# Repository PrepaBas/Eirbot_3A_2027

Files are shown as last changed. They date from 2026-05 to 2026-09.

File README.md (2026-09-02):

# EIRBOT 3A 2027
## Equipe
### OG
- Barthere Aurelien E3
- Bromet Alexandre E3
- Daragnes Leïa I3
- Guigui Marceau E3
- Halimi Zakaria E3
- Louvel Elise E3
- Marie Quentin E3
- Tran-Ruesche Bastien E3

#### A traquenard
- Berthod Hugo E3
- Donias Arno I3
- Michaud Lou-Ann E3
- Maxime Lavit E3
- Joan Dumarchat I3 (bientôt)

#### Refus
- 

## Compilation micro-ros
checkout to humble then go back to main folder and
``` bash
docker pull microros/micro_ros_static_library_builder:humble
docker run -it --rm -v $(pwd):/project --env MICROROS_LIBRARY_FOLDER=micro_ros_stm32cubemx_utils/microros_static_library microros/micro_ros_static_library_builder:humble
```

## Debug config
debug : Cortex-Debug dans vs code
+ `sudo apt install openocd`
+ fichier `.vscode/launch.json`
```json
{
    "version": "0.2.0",
    "configurations": [
        {
            "name": "Debug STM32H533 (micro-ROS)",
            "type": "cortex-debug",
            "request": "launch",
            "servertype": "openocd",
            "cwd": "${workspaceRoot}",
            "executable": "${workspaceRoot}/build/microros_base.elf",
            "device": "STM32H533RE", // Ajuste si la référence exacte de ton H5 change
            "configFiles": [
                "interface/stlink.cfg",
                "target/stm32h5x.cfg"
            ],
            // --- TRÈS IMPORTANT POUR EUROBOT & FREERTOS ---
            "rtos": "FreeRTOS", // Permet à VS Code de voir tes différentes tâches (Odom, micro-ROS...)
            "runToEntryPoint": "main", // S'arrête automatiquement au début du main()
            "openOCDPreConfigLaunchCommands": [
                "set CONNECT_UNDER_RESET 1" // Évite le piège du blocage de la puce !
            ]
        }
    ]
}
```
## Esthétique du robot
???
## Méca
### Structure
Une plaque de 5mm (acrilique, aluminium ou acier) de 250x250mm avec les coins coupés à 5mm du sol. une bille principale à l'arrière et des patins de protection partout autour. (A voir pour une plaque de 240x240mm mais en rajoutant du flexible en protection).  
Des makerbeam (extrusion aluminium de 10x10mm) s'attachent à la plaque horizontalement et une tour de quatre extrusions s'élève jusqu'à h=30mm. En haut, d'autres extrusions forment une base pour monter l'électronique, un écran, une balise, l'aru...

### Bloc moteur
Stepper Nema 17 avec encodeuse As5047p. Contrôlé (FOC) par ST B-g431Esc suivant le modèle HybridStepper de SimpleFOC.  
Roue encodeuse sur table suspendue par deux rails linéaires MGN9H, MGN12C ou MGN12H. Roues sur deux roulements et encodée avec le capteur magnétique As5047p encore une fois. Force linéaire descendante avec des élastiques de bureau.  
Cet ensemble s'attache à la plaque du dessous. Les vis sont fraisées et montée par le dessous. L'alignement est à voir. 
Roues de romba ou tube silicon ou silicon de cuisine...

### Matériaux
Du plastique imprimé en 3D / de l'acrylique découpé à la laser et eventuellement du métal si on a les moyens vers la fin.
Des makerbeam pour tout le reste du structurel.

### Visserie
du chc de préference

## Elec
### Puissance
J'ai deux batteries lipo 4s (15V) mais ca va être compliqué de mettre les deux sur le robot parce qu'elles sont grosses. Donc robot en 12V à part si on trouve une solution pour caser les deux / racheter des batteries plus petites.  
prévoir 
- 5.2V 5A en USB-C pour la rasp
- 2x 12V 2.5A pour les moteurs (et pas mal de réserve en pic)
- rails 12V et 5V pour actionneurs et capteurs

##### Et eventuellement
- 5V 0.5A en USB-C pour la STm
- 

#### Connectique
XT-30 : femelle donne et mâle reçoit.

#### Protection
Fusible au moins mais je ne m'y connais pas

### Logique
Acheter des fils petits c'est beaucoup mieux. JST 2.5mm c'est pour l'instant le plus pratique même si c'est gros

### Ventilation
Ce serai bien d'en mettre

## Info
### Rasp
#### Ecran
Ecran tactile si possible avec une interface graphique (html par exemple) qui permet d'executer des scripts.

#### ROS2
Framwork Ros2 dans un docker pour pouvoir laisser raspOS en natif. Le but est de commencer à écrire nos propres nodes. La strat générale c'est d'utiliser les Behavior Tree pour séquencer les actions : il faut donc faire des serveurs
- rotation
- ligne droite
- path planning sommaire pour éviter nav2
- actionneurs

Il faut aussi faire la détection et tout enfin bref une belle galère.  
Exit gazebo vive rviz tout court  

EKF pour les roues odometriques, l'imu et autre si affinité.

Exit le controller differentiel de ros, ca se fera sur mcu.

#### Behavior Tree
Permet de rendre le robot dynamique. Par exemple, recherche d'un goal, séquence pour arriver au goal, maneuvre et actionneurs et rebelotte. Si un obstacle est détecté, on peut attendre et réessayer avant de revenir au choix de l'action.

Dans l'idéal il y a un serveur en python (rasp) et un serveur en c++ (mcu) pour distinguer la simu du réel.

### MCU
STM32 mp1814C qui embarque un st32h533re bien balèze. Host micro-ros pour communiquer avec le ros2 de la rasp. 
Programmation hors framework Arduino donc avec la synthaxe ST et la configuration sur CubeMX. L'utilisation de micro-ros 'impose' une toolchain Makefile.  
Le MCU doit gérer : 
- Envoi des commandes CAN de vitesse aux ESC
- Reception des données encodeuses. Signaux AB récupérés avec les timers en mode encoder.
- Asserv rapide et capacité de tourner, avancer (voir se déplacer dans le plan mais on est pas encore là).
- Récupération via SPI de l'IMU **ICM42688**
- Récupération des données TOF si il y a
- Gestion des timeout, de l'évitement de poing, du timer de 100 secondes : il faut donc plusieurs modes pour le debug et le match (pourquoi pas un topic)
- des serveurs pour tourner, avancer et faire marcher les actionneurs.

## Evitement
Un lidar si on veut, branché sur la rasp et qui permet de faire de l'évitement longue distance  
Des tof branchés au MCU pour la défense de poing.

Dans le meilleur des mondes des zones (devant près, devant loin, droite près ...) pour éviter de tourner avec les actionneurs déployés.

## Répartition des tâches
Le robot contient deux centres de calculs principaux : le microcontroleur et le microprocesseur.  
> **Le processeur** gère la stratégie haut niveau, la connectivité réseau et l'aquisition et traitement lidar.

> **Le controlleur** gère le controle moteur, l'estimation de position à partir de [encodeuse, centrale inertielle, position absolue résultant du traitement lidar].

Pourquoi? Le controlleur doit gérer le controle moteur le plus précisement possible, et à donc besoin de faire ses calculs en temps réel le plus possible. Le processeur est utile surtout pour la connectivité et sa puissance de calcule au détriment du temps réel. Pour cela ce dernier est réserver à la strat et traitement lidar qui sont respectivement peu critique et lourd en calculs.  
Eventuellement le controlleur peut avoir des élements de détection rapprochés type tof pour une sécurité supplémentaire, et le processeur un algorithme de path planning pour générer des trajectoires courbes.

```Mermaid
C4Component
    title Diagramme C4 - Architecture Microcontrôleur & Raspberry Pi

    System_Boundary(main_robot, "Robot Principal", "Gros robot", "rien") {

        Component_Ext(mag_sens, "As5047p", "Capteur", "Capteur magnétique angle absolue")
        Component_Ext(imu_sens, "ICM42688", "Capteur", "Acceleromètre et gyroscope")
        Component_Ext(lidar, "RPLidar C1", "Capteur", "LIDAR")

        Container_Boundary(mcu, "Microcontrôleur STM32 (Micro-ROS)") {
            Component(t_as5047p, "Encoder-mode Timers", "Hardware", "Aqueri les signaux AB des encodeurs")
            Component(t_imu, "IMU DMA", "Hardware / RTOS Task", "Aqueri les données inertielles")
            Component(t_mot, "Tâche Moteur", "RTOS Timer", "Calcule la vitesse des moteurs (~100Hz)")
            Component(t_sens, "Kalman Filter", "Function", "Lit les données des capteurs physiques")
        }
        Container_Boundary(rpi, "Raspberry Pi (ROS2) ") {
            Component(t_lidar, "sllidar", "Ros2 Node", "Interface le RPLidar-C1 avec Ros2")
            Component(t_obj_det, "Object Detection", "Ros2 Node", "Extrait des formes depuis les données LIDAR")
            Component(t_trig, "Triangulation Balises", "Custom Ros2 Node", "Extrait une position absolue des objets détectés par le LIDAR")
            Component(t_adv_det, "Triangulation Adversaire", "Custom Ros2 Node", "Extrait une position absolue de l'adversaire")
        }
        Container_Boundary(mot, "Bloc Moteur") {
        Component_Ext(esc, "Bg431ESC", "Controlleur de viteses", "Contrôle les moteurs FOC (~20kHz)")
        Component_Ext(mag_sens_esc, "As5047p", "Capteur magnétique", "Angle absolue des roues")
        }
    }    

    %% Communications internes RPi
    Rel(t_lidar, t_obj_det, "Scan")
    Rel_L(t_obj_det, t_trig, "obj")
    Rel_R(t_obj_det, t_adv_det, "obj")
    
    %% Communication internes MCU
    Rel_D(t_sens, t_mot, "pose")
    Rel_D(t_imu, t_sens, "pose")
    Rel_D(t_as5047p, t_sens, "pose")

    %% Communications Rasp - MCU
    Rel_L(t_trig, t_sens, "lidar pose")

    %% Communication internes ESC
    Rel(mag_sens_esc, esc, "SPI : angle absolu")

    %% Communication Robot - MCU
    Rel(t_mot, esc, "CAN : vitesse des roues")
    Rel(mag_sens, t_as5047p, "Signaux AB")
    Rel(imu_sens, t_imu, "SPI")

    %% Communication Robot - Rasp
    Rel(lidar, t_lidar, "câble USB")

```

``` Mermaid
graph TD
    %% Node Styles
    classDef selector fill:#f9f,stroke:#333,stroke-width:2px;
    classDef sequence fill:#bbf,stroke:#333,stroke-width:2px;
    classDef condition fill:#ff9,stroke:#333,stroke-width:1px;
    classDef action fill:#9f9,stroke:#333,stroke-width:1px;

    %% --- LEGEND ---
    subgraph Legend ["Tree Legend"]
        direction LR
        L1{?}:::selector === L1_T["Selector (Runs until a child SUCCEEDS)"]
        L2[➔]:::sequence === L2_T["Sequence (Runs until a child FAILS)"]
        L3([Condition]):::condition === L3_T["Check / State Test"]
        L4[[Action]]:::action === L4_T["Execution / Behavior"]
    end

    %% --- BEHAVIOR TREE ---
    Root((Root)) --> Selector1{?}:::selector
    
    %% Fallback 1: Attack Branch
    Selector1 --> Sequence1[➔ Sequence: Fight]:::sequence
    Sequence1 --> Cond1([Is Enemy Close?]):::condition
    Sequence1 --> Act1[[Attack Enemy]]:::action
    
    %% Fallback 2: Patrol Branch
    Selector1 --> Sequence2[➔ Sequence: Patrol]:::sequence
    Sequence2 --> Cond2([Is Energy High?]):::condition
    Sequence2 --> Act2[[Move to Waypoint]]:::action
    
    %% Fallback 3: Rest Branch
    Selector1 --> Act3[[Sleep/Recover]]:::action
```

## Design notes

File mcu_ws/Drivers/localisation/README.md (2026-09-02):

# Localisation
## Kalman Filter
### Hardware
`kalman_filter.c/h` is a very simple implmentation of an Extended Kalman Filter (EKF) adapted to Eurobot for a differential drive robot using 3 sensors :
- Tables encoder wheels to track the robot's movement on the table isolated from the driving wheels. These are build using As5047p magnetic encoder wheels suspended on linear rails.
- A gyroscope to track the rotation rate. The icm42688 module also gives access to an accelerometer but it is unsed for odometry
- An rpLIDAR C1. This LIDAR works in conjunction with three or more beacons (reflective surfaces) placed on the sides of the table to triangulate the robot's position.  

Even if table wheels encoder and LIDAR could give the robot's odometry, each sensor track one aspect of the movement better than the others. The table wheels excels at mesuring linear movement, the gyroscope gives precise data about rotation rate and the LIDAR gives an absolute position of the robot eliminating any potential drift.

Most importantly, the accelerometer mounted with the gyroscope cannot be used to track linear movement as the error accumulates too fast over time. Additionaly, the LIDAR is too slow (data aquisition and processsing) to give real time odometry data. That is why combining sensors is something to want.

### Aquisition
#### Lecture encodeueses `As5047p`
Ce capteur magnétique peut lire l'angle d'un aimant placé devant lui. La lecture de l'angle peut se faire en SPI mais ici on préfère décoder les signaux en quadrature dit 'AB' que l'as5047p peut générer.  
Le but est d'utiliser les timer STM32 en mode encoder : deux channels d'un timer peuvent faire l'aquisition des signaux AB générés par l'`as5047p`. Dans cubeMX il faut mettre les timer 2 et 5 car ce sont les plus performants et sont sur *32 bits*. Le `Combined Channels` doit être `Encoder Mode`, dans les paramètres en bas le `Encoder Mode` doit être sur TI1 et TI2 pour que la quadrature se fasse. Sur un compteur 32bits, le compteur peut aller jusqu'à 4,294,967,295 ce qui permet de faire (/4000) 1 million de tour de roue sans overflow.  
L'underflow est par contre possible mais tout à fait utile en castant la valeur du compteur en signé `int32_t` dans le programme (alors que le compteur est uint32), ce qui permet d'avoir le compteur **centré en 0**.  
Ainsi l'aquisition des encodeuses se fait sans interuption supplémentaire et ne prend donc pas de cycle de calcul :)  

[outdated] Avec la cinématique inverse, on retrouve la vitesse des roues encodeuses $\dot \omega_r$ et $\dot \omega_l$, et donc la vitesses $\dot x$ et $\dot y$ de la base, mais aussi sa vitesse angulaire $\dot \theta$  qui serviron à estimer la position du robot, dans un filtre Kalman par exemple.

L'initialisation se fait avec la fonctin `
  HAL_TIM_Encoder_Start(&htim2, TIM_CHANNEL_ALL);`. La lecture des tick mesurés par les timer se font avec la fonction via l'objet timer `TIM2->CNT`. Il ne manque plus qu'à faire la difference avec la précedente mesure et retrouver la distance parcourue par chaque roue encodeuse.

#### Lecture centrale inertielle `ICM42688`
L'ICM42688 est un capteur d'acceleration et de rotation, donc de 6 valeurs (x, y, z pour chaque). Celà veut dire une lecture des registres en commande SPI de manière assez fréquente (>500Hz). Pour celà, la centrale génère une interuption via ses pin (le interrupt 1), et une lecture des registres peut ainsi suivre. Pour encore moins d'utilisation des cycles, il est possible d'utiliser la lecture en Direct Memory Access (DMA) ce qui donne l'execution suivante : interuption levée -> Envoi de la commande et lecture des registres en DMA en background -> interruption du DMA pour signaler la fin de l'aquisition -> calcul léger pour intégrer les valeurs.  
De manière moins fréquente, l'accumulation des valeurs peut être utilisée pour estimer l'état du robot dans un filtre Kalman par exemple.  

Il faut donc :
- **Un SPI** - ici le 2, le 1 étant restrint par le timer2 dand cubeMX. Préscaler de 16 pour rester en dessous de 24MHz, mots de 8 bits. Channel DMA en PAS circular car on sait à l'avance combient d'octets on veut lire. Bien selectionner le `Request` et configurer le `Direction` en conséquence. Pour les deux channel faire en sorte que l'incrément d'adresse se fasse sur la ram et non pas sur l'IMU.
- **Le pin CS** pour compléter le SPI (le mettre rapide).
- **Un pin d'intéruption** qui est activé par l'IMU. Cette intéruption doit trigger un sémaphore/notification pour mettre CS bas et déclencher la transmission DMA dans une tâche.

Une fonction d'envoi SPI consist à : 1.préparer le packet, 2.baisser le CS, 3.trasmettre avec `HAL_SPI_Transmit`, 4.remonter le CS.  
On utilise cette fonction pour configurer l'IMU.  

Les intéruptions utilisent le système de notificatin (similaire au sémaphore) pour débloquer la tâche principale. Il faut juste donner la *handle* de la tâche (récupérée avec`xTaskGetCurrentTaskHandle()`) et utiliser les fonctions `ulTaskNotifyTake(pdTRUE, portMAX_DELAY)` et `TaskNotifyGiveFromISR(imu.notified_task_handle, &xHigherPriorityTaskWoken)`. A noter qu'on ajoute la fonction `portYIELD_FROM_ISR(xHigherPriorityTaskWoken)` dans l'intéruption pour être sur de changer de tâche rapidement.

Le résultat des mesures peut être mis dans des variables globales ect mais de manière plus sécurisé on utilise les queue. On créé une queue et on récupère sa *handle* `imu_queue_handle = xQueueCreate(3, sizeof(imu_data_t))`, et à la fin du traitement on poste les données `xQueueSend(imu_queue_handle, &package, 0)`. Dans une autre tâche (kalman par exemple) on attend puis récupère les données `if (xQueueReceive(imu_queue_handle, &imu_packet, portMAX_DELAY) == pdPASS) {..}.`

Ensuite il faut parser les données pour pouvoir les utiliser.

### Le filtre de Kalman
L'odométrie du robot peut se faire de plusieurs façons :
- j'ai demandé telle et telle vitesse à mes roues, je peux donc savoir ou je vais être à l'instant suivant
- Mes capteurs ont mesuré un déplacement de 3cm, je sais donc ou je me trouve à partir de ma position précédente
- Mon lidar à permis de me trianguler en x- y-, c'est donc ici que je me trouve.

Celà permet de faire la distinction entre trois type de donnée : **La prédiction** (le calcul à partir des info déjà aquises); **l'estimation relative** (à partir d'une donné précedente) et **l'estimation absolue** (indépendant de l'état précedent). 
La prédiction est bien car elle permet à tout moment d'estimer l'état futur mais est sujette à la dérive car une commande ne se traduit jamais parfaitement dans la réalité. 
L'estimation relative (dead reckoning) permet d'avoir une donnée supplémentaire en ajoutant un capteur qui va mesurer une donnée réelle. Cependant, même si il peut mieux traduire le comportement réel du robot il est toujours victime d'une dérive avec le temps. 
L'estimation absolue en se fie pas du tout à l'état passé et trouve une position absolue pour le robot en se basant par exemple sur un lidar, gps, ect. Cette estimation ne dérive pas mais est souvent bruitée ou en retard ne la rendant pas viable pour un système rapide ou très précis.

Pour utiliser les forces et faiblesses de toutes ces estimations, on va essayer de faire de la **fusion de capteur**. C'est à dire se fier tout le temps aux calculs mathématiques si notre modèle n'est pas trop mauvais, écouter les capteurs relatifs car ils reflètent mieux la réalité et enfin écouter les capteurs absolue pour éliminer la dérive. C'est l'objectif d'un filtre de Kalman.  
Cependant le filtre ne fait pas une simple moyenne des capteurs. Il joue avec les incertitudes pour savoir si une donnée doit être prise en compte ou pas. Dans les faits on définit des matrices de bruit pour les maths (traduit un peu la réalité eg une table mal faite) et les capteurs. A chaque calcul mathématique, l'erreur est propagée (logique on est de moins en moins sur de où on est). A chaque donnée, le filtre Kalman va mathématique donner du poid ou non à la mesure suivant son bruit et le l'incertitude atteinte par le systeme, et l'intégrer à la position du robot. 
Celà fait en sorte qu'une mesure bruitée ne pertube pas une position certaine et à l'inverse qu'une position incertaine soit complémentée par une mesure (même bruitée).

>**Les équations** sont les suivantes ($f$ est une fonction non linéaire donc on utilise un filtre de kalman étendu)
>- **Prédiction** (à Priori)
    - Prédiction d'êtat $$\hat x_{k|k-1} = f(\hat x_{k-1|k-1}, u_{k-1})$$
    - Prédiction de covariance $$P_{k|k-1} = F_k P_{k-1|k-1}F^T_k + Q_{k-1}$$
>- **Correction** (à Postériori)
    - Innovation $$\tilde y_k = z_k - h(\hat x_{k|k-1})$$
    - Covariance de  l'innovatin  $$S_k = H_k P_{k|k-1} H^T_k + R_k$$
    - Gain de Kalman quasi-optimal $$K_k = P_{k|k-1} H^T_k S^{-1}_k$$
    - Etat mis à jour $$\hat x_{k|k} = \hat x_{k|k-1} + K_k \tilde y_k$$
    - Covariance mise à jour $$P_{k|k} = (I - K_kH_k)P_{k|k-1}$$
>avec 
    - Matrice d'évolution $$F_k = \frac{\partial f}{ \partial x}|_{\hat x_{k-1|k-1},  u_{k-1}}$$
    - Matrice d'observation $$H_k = \frac{\partial h}{ \partial x}|_{\hat x_{k|k-1}}$$

On distingue plusieurs variantes :
- $\hat x_{k|k}$ l'estimation de x que l'on cherche à calculer (prédiction plus correction)
- $ \hat x_{k|k-1}$ l'estimation (aucune nouvelle donnée seuelement les commandes)
- $\hat x_{k-1|k-1}$ ancienne donnée ($\hat x_{k|k}$ du cycle d'avant)
a confiance en la position
- $z_k$ est la mesure
- $F$ est la jacobienne de l'équation de propagation. Equation de propagation qui prend les commandes utilisateur et calcul l'état suivant théorique  
- $P$ porte l'incertitude de la position $x$ sous forme de covariances  
- $Q$ porte l'incertitude qui doit être rajouté par la simple existance du système (glissement ..)  
- $H$ sert à transposer la donnée capteur (ou la différence si on parle de l'innovation) sous le format du vecteur d'êtat (e.g., vitesse(capteur) * $\Delta t$ )  
- $R$ traduit le bruit de la mesure. Propre à chaque capteur  
- $S$ est juste la matrice à inverser pour le gain de Kalman. (elle met le bruit de mesure au dénominateur)
 
**Remarque** : Il n'y à aucun bruit dans les équations parce que cette donnée est contenue dans les matrices $Q$ et $R$. Une modélisation de la réalité est $x_k = Fx_{k-1} + Bu_k+ bruit$ mais le but du filtre est d'abstraire ce bruit et de le filtrer de manière probabilistique.

>**Prédiction robot différentiel**
>- **Données** : $v_l$ et $v_r$ la commande de vitesse (à $t=k-1$) au sol des roues, $L$ l'entraxe (roues motrices)
>- **Vecteurs êtat** et **commande** : $$\hat X = \begin{bmatrix}x \\y \\\theta\end{bmatrix} , U= \begin{bmatrix}v_l \\ v_r \\\end{bmatrix}$$
>- **Equations de propagation** $f(\hat x_{k-1|k-1}, u_{k-1})$ : $$x_k = x_{k-1} + \frac{v_l + v_r}{2} cos(\theta_{k-1})\Delta t$$ $$y_k = y_{k-1} + \frac{v_l + v_r}{2} sin(\theta_{k-1})\Delta t$$ $$\theta_k = \theta_{k-1} - \frac{v_l - v_r}{L} \Delta t$$
> =>$$F= \begin{bmatrix} 1 & 0 & -\frac{v_l + v_r}{2} sin(\theta_{k-1})\Delta t \\ 0 & 1 & \frac{v_l + v_r}{2} cos(\theta_{k-1})\Delta t \\ 0 & 0 & 1 \end{bmatrix}$$
>- **$P$** (3x3) est recalculée en permanance. Sa valeur initiale peut être 0 si on est sûr de la position du robot (repositionnement).
>- **$Q$** (3x3) est normalement dynamique en fonction de la vitesse du robot qui fait augmenter l'incertitude de la prédiction. Cependant une matrice constante déterminée empiriquement est beaucoup plus simple à mettre en place. Des valeurs élevées vont faire que les capteurs seront beaucoup plus pris en compte et inversement.

---

>**Correction avec LIDAR**  
>Techniquement on peut garder le formalisme matriciel et avoir $H$ de taille (6x3) mais en pratique ce n'est pas pratique car les données n'arrivent pas en même temps et les calculs sont très lourds. On préfère faire correction par correction (ce qui revient au même car c'est des multiplications) pour gagner en flexibilité.
>- **LIDAR** triangulé donne une position de la même forme que le vecteur d'état.  
    - $H = \begin{pmatrix} 1&0&0\\0&1&0\\0&0&1\\\end{pmatrix}$ et $R$ à définir suivant la précision du positionnement

---

>**Et mes autres capteurs?????**  
> **/!\\** En fait on va pas du tout faire comme la théorie et plutot utiliser **les roues encodeuses** et **la centrale inertielle** pour faire la prédiction. *Contre-intuitif?? Bah oui...*  
Ducoup les **roues encodeuses** vont nous donner une donnée de distance parcourue dont on gardera que la distance linéaire (demi-somme des distance des deux roues).  
L'**IMU** lui va donner la donnée de rotation sur l'axe z, les autres données (acceleromètre et les deux autres axes du gyroscope) ne sont pas utilisées.   
On utilise les valeurs dans un nouveau vecteur commande.
>
> Pourquoi il faut faire ça? En fait pour utliser ces deux capteurs en correction, il faudrait avoir un vecteur d'êtat de taille (5x5) ce qui alourdit enormement les calculs. Ca permet aussi de ne pas avoir à calculer une prédiction mathématique, qui dans tous les cas n'est pas vraiment possible par manque d'un modèle fiable. Donc dans notre montage on est plutot sur une odométrie avec encodeueses et gyroscope normale mais avec une correction LIDAR pondérée.  
C'est pas cool mathématiquement mais on fait de la robotique donc OSEF. Les calculs sont quasiment les même donc je les écris pas. juste $U = \begin{pmatrix} d & \omega \\\end{pmatrix}^T $.

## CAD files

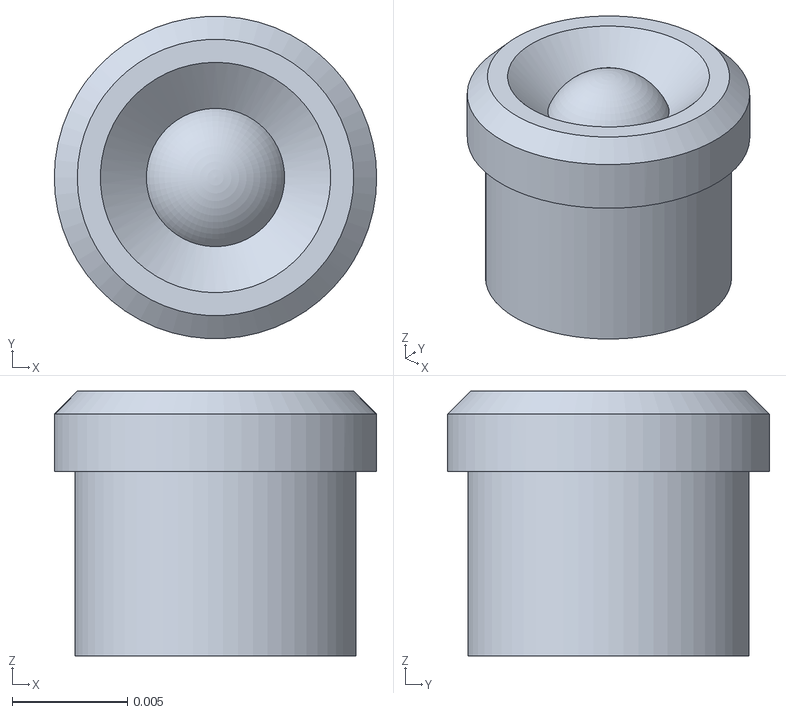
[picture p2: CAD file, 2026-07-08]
ros2_ws/src/robot_description/meshes/detector_igs.stl
0.014 x 0.014 x 0.0115

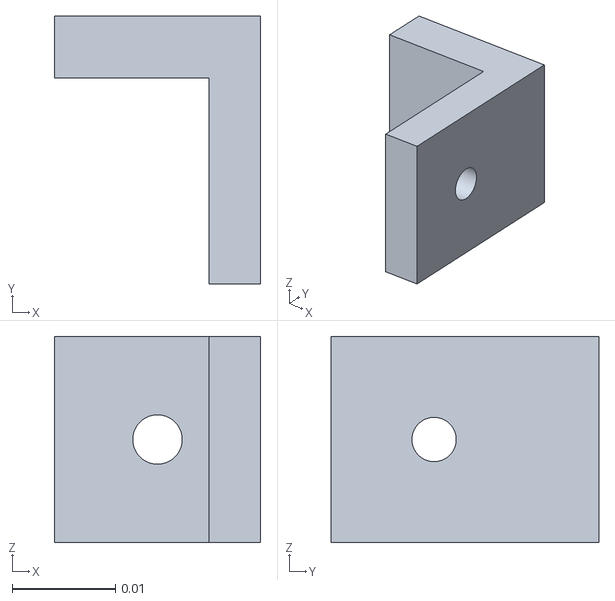
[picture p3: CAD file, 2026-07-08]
ros2_ws/src/robot_description/meshes/Part_2_5.stl
0.02 x 0.026 x 0.02

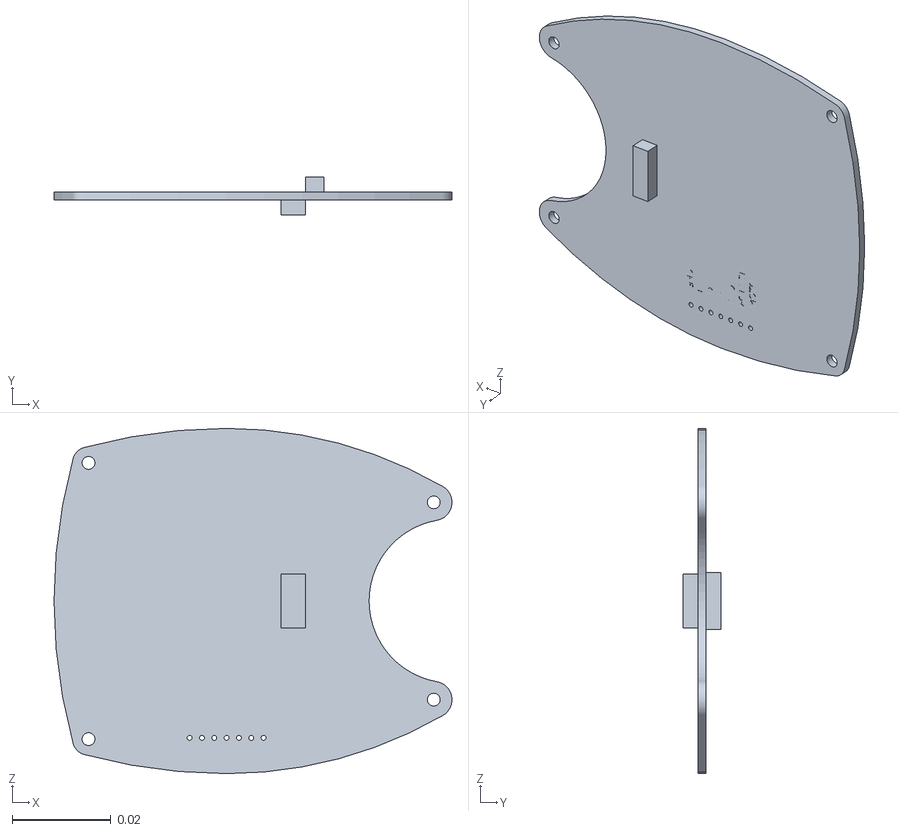
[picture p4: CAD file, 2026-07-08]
ros2_ws/src/robot_description/meshes/devboard_igs.stl
0.0807 x 0.00764 x 0.07

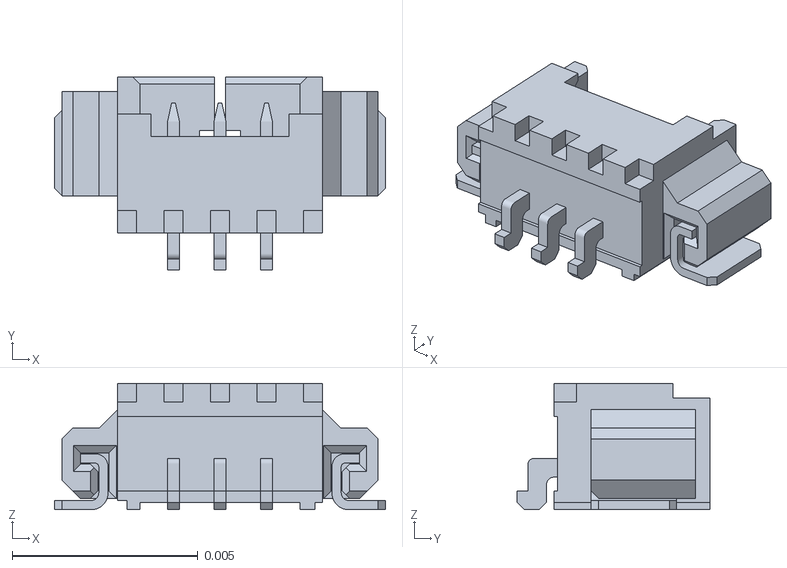
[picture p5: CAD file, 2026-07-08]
ros2_ws/src/robot_description/meshes/connector_1_25_3pin_igs.stl
0.0089 x 0.0052 x 0.0034

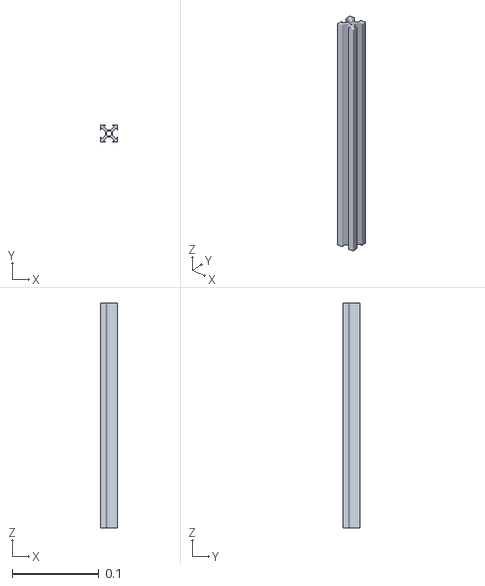
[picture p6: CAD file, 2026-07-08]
ros2_ws/src/robot_description/meshes/Part_1_12.stl
0.02 x 0.02 x 0.26

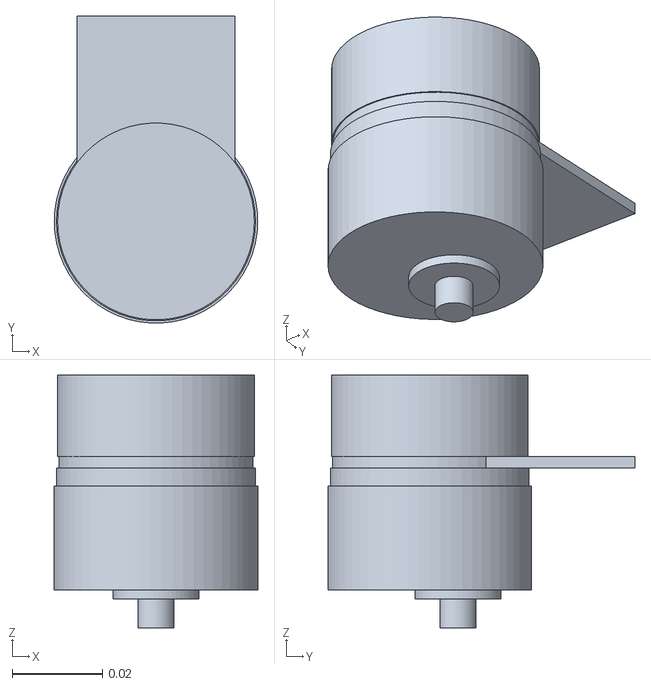
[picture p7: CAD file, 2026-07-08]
ros2_ws/src/robot_description/meshes/Part_1_7.stl
0.045 x 0.0679 x 0.0559

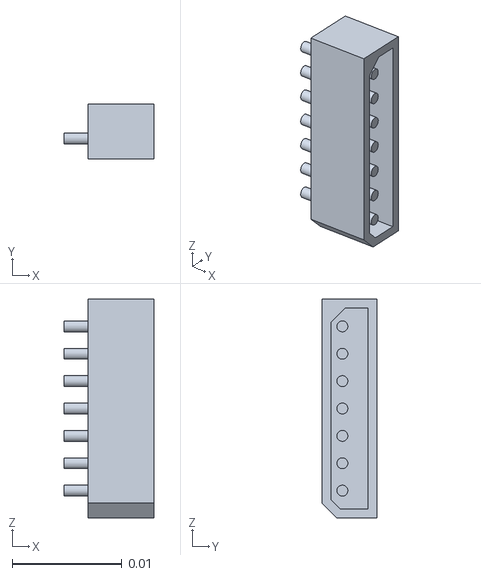
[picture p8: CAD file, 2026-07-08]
ros2_ws/src/robot_description/meshes/connector_7pin_2_5_igs.stl
0.0082 x 0.005 x 0.02

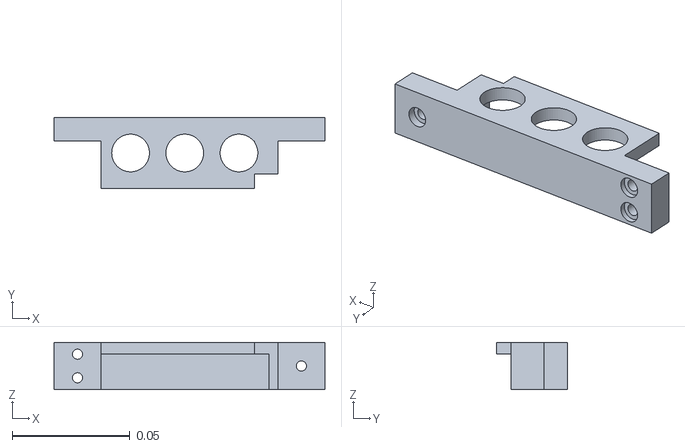
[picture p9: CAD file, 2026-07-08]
ros2_ws/src/robot_description/meshes/Part_3_1.stl
0.115 x 0.03 x 0.02

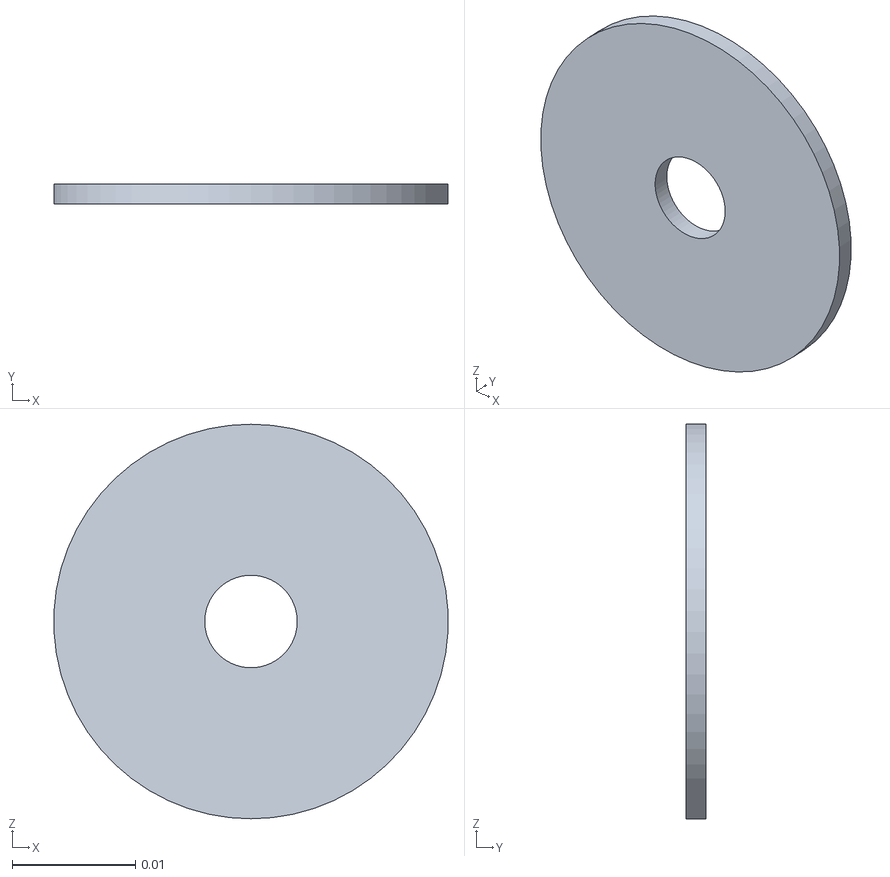
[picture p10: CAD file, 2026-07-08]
ros2_ws/src/robot_description/meshes/motor_board_igs.stl
0.032 x 0.0016 x 0.032

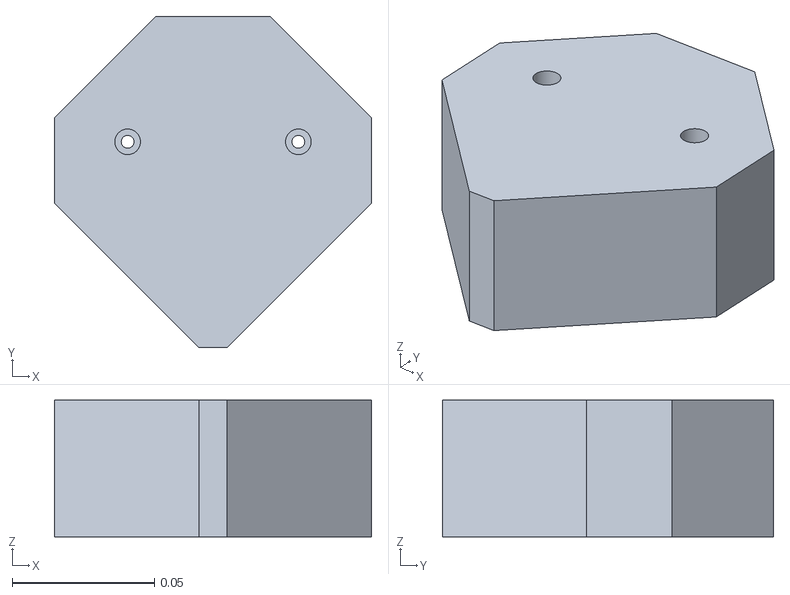
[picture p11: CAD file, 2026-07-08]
ros2_ws/src/robot_description/meshes/Part_4.stl
0.111 x 0.116 x 0.048

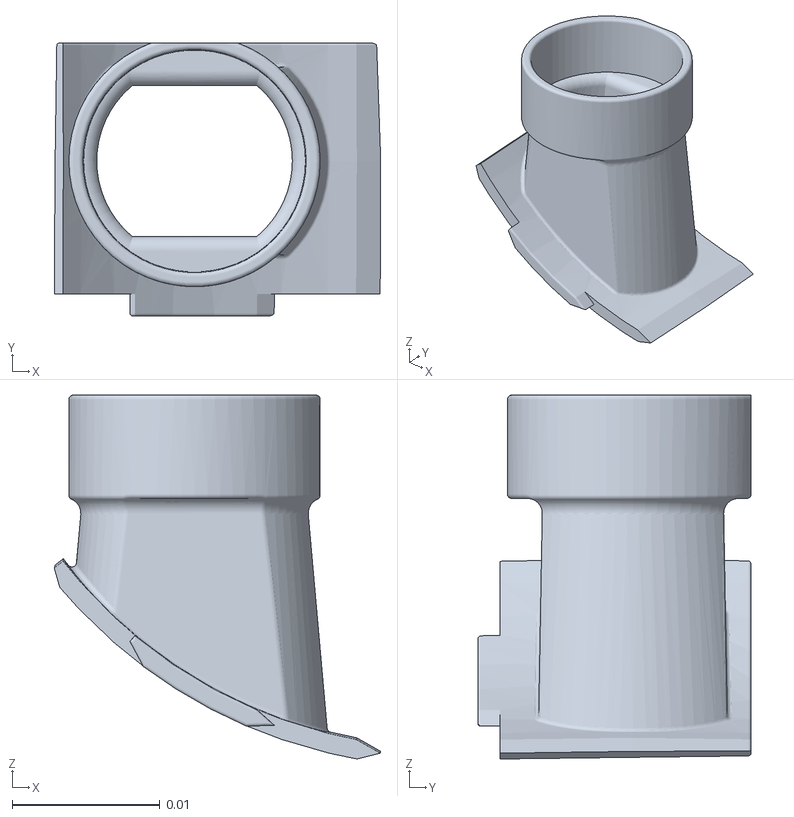
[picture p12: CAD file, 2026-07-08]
ros2_ws/src/robot_description/meshes/detector_mount_igs.stl
0.0221 x 0.0185 x 0.0246

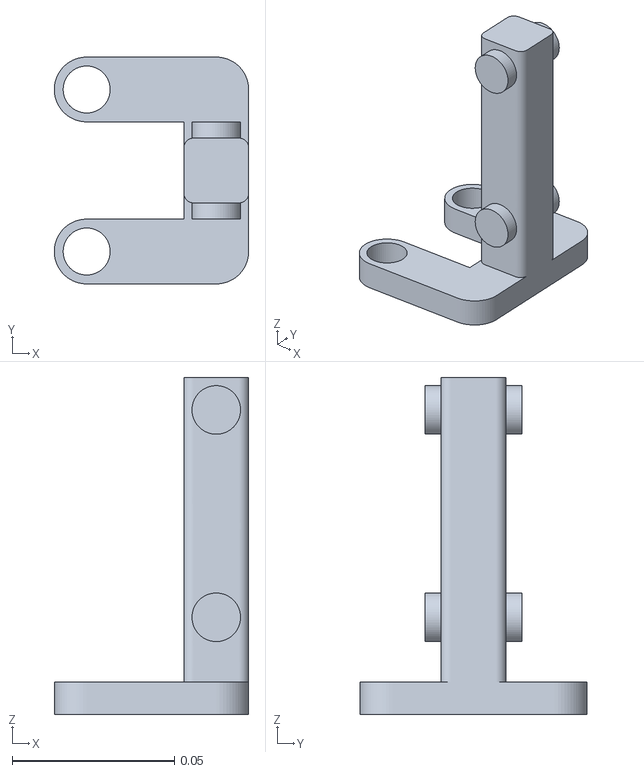
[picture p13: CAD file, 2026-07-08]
ros2_ws/src/robot_description/meshes/Part_1_5.stl
0.06 x 0.07 x 0.104

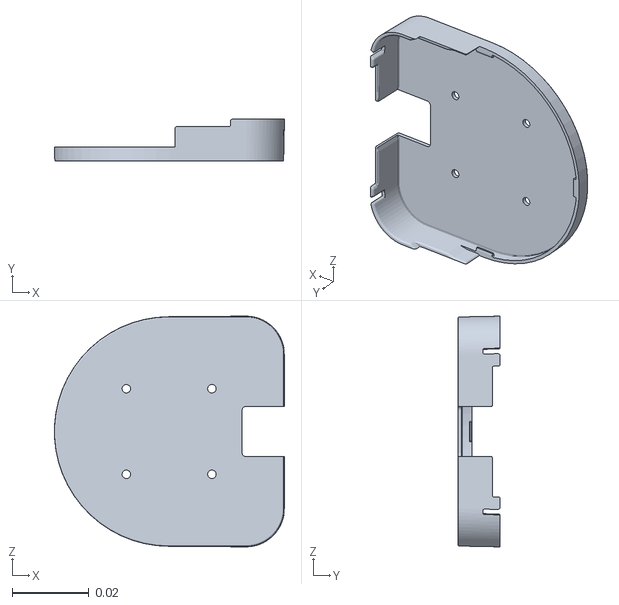
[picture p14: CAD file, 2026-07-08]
ros2_ws/src/robot_description/meshes/bottom_lid_igs.stl
0.0599 x 0.011 x 0.0601

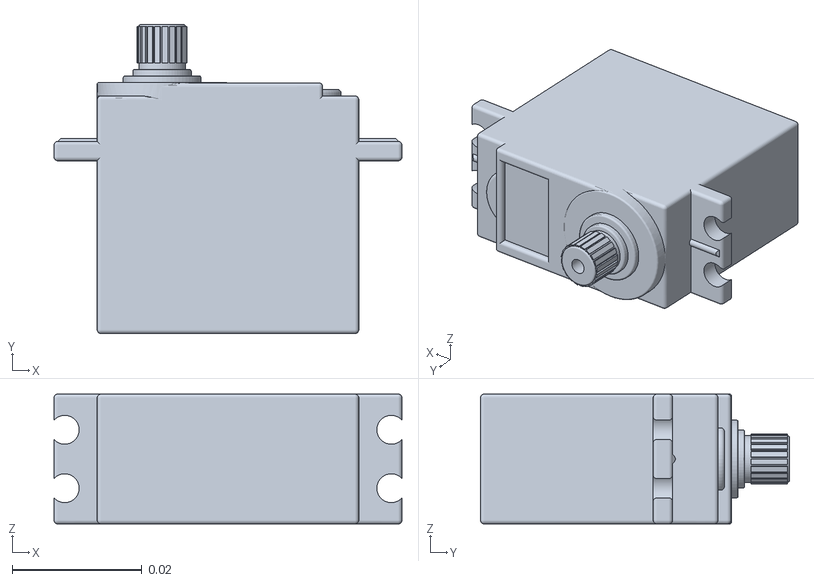
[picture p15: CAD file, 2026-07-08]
ros2_ws/src/robot_description/meshes/Servo_MG996R.stl
0.0536 x 0.0476 x 0.02

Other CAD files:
ros2_ws/src/robot_description/meshes/Part_1_6.stl
ros2_ws/src/robot_description/meshes/Part_1_9.stl
ros2_ws/src/robot_description/meshes/Part_2_2.stl
ros2_ws/src/robot_description/meshes/Part_2_3.stl
ros2_ws/src/robot_description/meshes/Banebots_t81_Wheel_2_875x_8.stl
ros2_ws/src/robot_description/meshes/Part_1.stl
ros2_ws/src/robot_description/meshes/Part_1_1.stl
ros2_ws/src/robot_description/meshes/Part_1_10.stl
ros2_ws/src/robot_description/meshes/Part_1_11.stl
ros2_ws/src/robot_description/meshes/Part_1_2.stl
ros2_ws/src/robot_description/meshes/Part_1_3.stl
ros2_ws/src/robot_description/meshes/Part_1_4.stl
ros2_ws/src/robot_description/meshes/Part_1_8.stl
ros2_ws/src/robot_description/meshes/Part_2.stl
ros2_ws/src/robot_description/meshes/Part_2_1.stl
ros2_ws/src/robot_description/meshes/Part_2_4.stl
ros2_ws/src/robot_description/meshes/Part_3.stl
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

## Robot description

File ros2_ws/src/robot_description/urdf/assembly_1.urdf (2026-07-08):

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
<robot name="assembly_1">
    <link name="banebots_t81_wheel_2_875x_8">
        <inertial>
            <mass value="6.53363e-05" />
            <origin xyz="-2.9392e-07 -9.46857e-11 -0.00769337" rpy="0 -0 0" />
            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
        </inertial>
        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
    </link>
    <link name="banebots_t81_wheel_2_875x_8_1">
        <inertial>
            <mass value="6.53363e-05" />
            <origin xyz="-2.9392e-07 -9.46857e-11 -0.00769337" rpy="0 -0 0" />
            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
        </inertial>
        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
    </link>
    <link name="parallel_1" />
    <link name="parallel_1_1" />
    <link name="parallel_1_2" />
    <link name="parallel_2" />
    <link name="parallel_2_1" />
    <link name="parallel_2_2" />
    <link name="parallel_2_3" />
    <link name="parallel_2_4" />
    <link name="parallel_2_5" />
    <link name="parallel_3" />
    <link name="parallel_3_1" />
    <link name="parallel_3_2" />
    <link name="parallel_3_loop_closure" />
    <link name="parallel_3_loop_closure_1" />
    <link name="parallel_3_loop_closure_2" />
    <link name="part_1">
        <inertial>
            <mass value="6.81831e-06" />
            <origin xyz="1.29632e-19 -1.74022e-19 -0.00208469" rpy="0 -0 0" />
            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
        </inertial>
        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
    </link>
    <link name="part_1_10">
        <inertial>
            <mass value="6.5818e-05" />
            <origin xyz="-0.0047134 0.015 -0.0568067" rpy="0 -0 0" />
            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
        </inertial>
        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
    </link>
    <link name="part_1_11">
        <inertial>
            <mass value="6.90227e-05" />
            <origin xyz="-0.0100031 -2.75449e-13 0.0730462" rpy="0 -0 0" />
            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
        </inertial>
        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
    </link>
    <link name="part_1_12">
        <inertial>
            <mass value="9.71819e-05" />
            <origin xyz="-0.01 0.000254186 0.0754659" rpy="0 -0 0" />
            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
        </inertial>
        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
    </link>
    <link name="part_1_13">
        <inertial>
            <mass value="7.62595e-05" />
            <origin xyz="-1.47914e-18 -0.00525072 0.0231932" rpy="0 -0 0" />
            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
        </inertial>
        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
    </link>
    <link name="part_1_14">
        <inertial>
            <mass value="5.96966e-05" />
            <origin xyz="-0.12 -0.0015 -0.045" rpy="0 -0 0" />
            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
        </inertial>
        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
    </link>
    <link name="part_1_15">
        <inertial>
            <mass value="0.000343268" />
            <origin xyz="0.153535 -0.0615052 0.138422" rpy="0 -0 0" />
            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
        </inertial>
        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
    </link>
    <link name="part_1_16">
        <inertial>
            <mass value="4.99659e-05" />
            <origin xyz="0.007 0.01 0.147708" rpy="0 -0 0" />
            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
        </inertial>
        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
    </link>
    <link name="part_1_17">
        <inertial>
            <mass value="5.90334e-06" />
            <origin xyz="-1.94978e-12 0.00376385 9.08945e-12" rpy="0 -0 0" />
            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
        </inertial>
        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
    </link>
    <link name="part_1_18">
        <inertial>
            <mass value="4.99659e-05" />
            <origin xyz="0.01 -0.01 -0.00229178" rpy="0 -0 0" />
            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
        </inertial>
        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
    </link>
    <link name="part_1_19">
        <inertial>
            <mass value="5.90334e-06" />
            <origin xyz="-1.94978e-12 0.00376385 9.08945e-12" rpy="0 -0 0" />
            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
        </inertial>
        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
    </link>
    <link name="part_1_2">
        <inertial>
            <mass value="9.92629e-05" />
            <origin xyz="-0.13 0.0043678 0.000701342" rpy="0 -0 0" />
            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
        </inertial>
        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
    </link>
    <link name="part_1_20">
        <inertial>
            <mass value="4.25687e-05" />
            <origin xyz="0.01 0.01 1.93814e-17" rpy="0 -0 0" />
            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
        </inertial>
        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
    </link>
    <link name="part_1_21">
        <inertial>
            <mass value="4.25687e-05" />
            <origin xyz="-0.01 0.01 1.93814e-17" rpy="0 -0 0" />
            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
        </inertial>
        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
    </link>
    <link name="part_1_22">
        <inertial>
            <mass value="4.25687e-05" />
            <origin xyz="0.01 0.01 1.93814e-17" rpy="0 -0 0" />
            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
        </inertial>
        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
    </link>
    <link name="part_1_23">
        <inertial>
            <mass value="5.90334e-06" />
            <origin xyz="-1.94978e-12 0.00376385 9.08945e-12" rpy="0 -0 0" />
            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
        </inertial>
        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
    </link>
    <link name="part_1_24">
        <inertial>
            <mass value="4.25687e-05" />
            <origin xyz="-0.01 0.01 1.93814e-17" rpy="0 -0 0" />
            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
        </inertial>
        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
    </link>
    <link name="part_1_25">
        <inertial>
            <mass value="5.90334e-06" />
            <origin xyz="-1.94978e-12 0.00376385 9.08945e-12" rpy="0 -0 0" />
            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
        </inertial>
        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
    </link>
    <link name="part_1_3">
        <inertial>
            <mass value="6.90227e-05" />
            <origin xyz="-3.07229e-06 -2.75447e-13 -0.0869538" rpy="0 -0 0" />
            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
        </inertial>
        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
    </link>
    <link name="part_1_4">
        <inertial>
            <mass value="9.15836e-06" />
            <origin xyz="0.000550906 -0.00486567 -4.06502e-19" rpy="0 -0 0" />
            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
        </inertial>
        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
    </link>
    <link name="part_1_5">
        <inertial>
            <mass value="6.5818e-05" />
            <origin xyz="-0.0047134 0.015 -0.0568067" rpy="0 -0 0" />
            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
        </inertial>
        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
    </link>
    <link name="part_1_6">
        <inertial>
            <mass value="9.15836e-06" />
            <origin xyz="0.000550906 -0.00486567 -4.06502e-19" rpy="0 -0 0" />
            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
        </inertial>
        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
    </link>
    <link name="part_1_7">
        <inertial>
            <mass value="9.71819e-05" />
            <origin xyz="1.61937e-17 -0.0147458 -0.0445341" rpy="0 -0 0" />
            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
        </inertial>
        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
    </link>
    <link name="part_1_8">
        <inertial>
            <mass value="9.15836e-06" />
            <origin xyz="0.000550906 -0.00486567 -4.06502e-19" rpy="0 -0 0" />
            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
        </inertial>
        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
    </link>
    <link name="part_1_9">
        <inertial>
            <mass value="9.15836e-06" />
            <origin xyz="0.000550906 -0.00486567 -4.06502e-19" rpy="0 -0 0" />
            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
        </inertial>
        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
    </link>
    <link name="part_1__1__loop_closure">
        <inertial>
            <mass value="1e-09" />
            <origin xyz="0 0 0" rpy="0 -0 0" />
            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
        </inertial>
    </link>
    <link name="part_1__1__loop_closure_1">
        <inertial>
            <mass value="1e-09" />
            <origin xyz="0 0 0" rpy="0 -0 0" />
            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
        </inertial>
    </link>
    <link name="part_1__2__loop_closure">
        <inertial>
            <mass value="1e-09" />
            <origin xyz="0 0 0" rpy="0 -0 0" />
            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
        </inertial>
    </link>
    <link name="part_1__3__loop_closure">
        <inertial>
            <mass value="1e-09" />
            <origin xyz="0 0 0" rpy="0 -0 0" />
            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
        </inertial>
    </link>
    <link name="part_1__4__loop_closure">
        <inertial>
            <mass value="1e-09" />
            <origin xyz="0 0 0" rpy="0 -0 0" />
            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
        </inertial>
    </link>
    <link name="part_1__4__loop_closure_1">
        <inertial>
            <mass value="1e-09" />
            <origin xyz="0 0 0" rpy="0 -0 0" />
            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
        </inertial>
    </link>
    <link name="part_1__6__loop_closure">
        <inertial>
            <mass value="1e-09" />
            <origin xyz="0 0 0" rpy="0 -0 0" />
            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
        </inertial>
    </link>
    <link name="part_2">
        <inertial>
            <mass value="2.26554e-05" />
            <origin xyz="9.23997e-18 -0.0220219 -0.00824128" rpy="0 -0 0" />
            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
        </inertial>
        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
    </link>
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

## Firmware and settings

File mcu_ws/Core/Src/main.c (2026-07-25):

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
/* Includes ------------------------------------------------------------------*/
#include "main.h"
#include "cmsis_os2.h"
#include "fdcan.h"
#include "gpdma.h"
#include "i2c.h"
#include "icache.h"
#include "spi.h"
#include "tim.h"
#include "usart.h"
#include "gpio.h"

/* USER CODE BEGIN Includes */
#include "stm32h5xx_hal.h"
#include "stm32h5xx_hal.h"
#include "stm32h5xx_hal_conf.h"

#include <rcl/rcl.h>
#include <rcl/error_handling.h>
#include <rclc/rclc.h>
#include <rclc/executor.h>
#include <uxr/client/transport.h>
#include <rmw_microxrcedds_c/config.h>
#include <rmw_microros/rmw_microros.h>

#include <std_msgs/msg/int32.h>
/* USER CODE END Includes */


void SystemClock_Config(void);
static void MPU_Config(void);
void MX_FREERTOS_Init(void);
/**
  * @brief  The application entry point.
  * @retval int
  */
int main(void)
{

  /* MCU Configuration--------------------------------------------------------*/

  /* MPU Configuration--------------------------------------------------------*/
  MPU_Config();

  /* Reset of all peripherals, Initializes the Flash interface and the Systick. */
  HAL_Init();

  /* Configure the system clock */
  SystemClock_Config();

  /* Initialize all configured peripherals */
  MX_GPIO_Init();
  MX_GPDMA1_Init();
  MX_ICACHE_Init();
  MX_USART2_UART_Init();
  MX_TIM2_Init();
  MX_TIM5_Init();
  MX_SPI2_Init();
  MX_FDCAN1_Init();
  MX_I2C1_Init();
  MX_TIM6_Init();
  /* USER CODE BEGIN 2 */
  
  DBGMCU->CR |= DBGMCU_CR_DBG_STOP | DBGMCU_CR_DBG_STANDBY;
  /* USER CODE END 2 */

  /* Init scheduler */
  osKernelInitialize();
  /* Call init function for freertos objects (in app_freertos.c) */
  MX_FREERTOS_Init();

  /* Start scheduler */
  osKernelStart();

  /* We should never get here as control is now taken by the scheduler */

  /* Infinite loop */
  /* USER CODE BEGIN WHILE */
  while (1)
  {
    /* USER CODE END WHILE */

    /* USER CODE BEGIN 3 */
  }
  /* USER CODE END 3 */
}

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
 /* MPU Configuration */

void MPU_Config(void)
{
  MPU_Region_InitTypeDef MPU_InitStruct = {0};
  MPU_Attributes_InitTypeDef MPU_AttributesInit = {0};

  /* Disables the MPU */
  HAL_MPU_Disable();

  /** Initializes and configures the Region 0 and the memory to be protected
  */
  MPU_InitStruct.Enable = MPU_REGION_ENABLE;
  MPU_InitStruct.Number = MPU_REGION_NUMBER0;
  MPU_InitStruct.BaseAddress = 0x08FFF000;
  MPU_InitStruct.LimitAddress = 0x08FFFFFF;
  MPU_InitStruct.AttributesIndex = MPU_ATTRIBUTES_NUMBER0;
  MPU_InitStruct.AccessPermission = MPU_REGION_ALL_RO;
  MPU_InitStruct.DisableExec = MPU_INSTRUCTION_ACCESS_DISABLE;
  MPU_InitStruct.IsShareable = MPU_ACCESS_NOT_SHAREABLE;

  HAL_MPU_ConfigRegion(&MPU_InitStruct);

  /** Initializes and configures the Attribute 0 and the memory to be protected
  */
  MPU_AttributesInit.Number = MPU_ATTRIBUTES_NUMBER0;
  MPU_AttributesInit.Attributes = INNER_OUTER(MPU_NOT_CACHEABLE);

  HAL_MPU_ConfigMemoryAttributes(&MPU_AttributesInit);
  /* Enables the MPU */
  HAL_MPU_Enable(MPU_PRIVILEGED_DEFAULT);

}

/**
  * @brief  Period elapsed callback in non blocking mode
  * @note   This function is called  when TIM1 interrupt took place, inside
  * HAL_TIM_IRQHandler(). It makes a direct call to HAL_IncTick() to increment
  * a global variable "uwTick" used as application time base.
  * @param  htim : TIM handle
  * @retval None
  */
void HAL_TIM_PeriodElapsedCdallback(TIM_HandleTypeDef *htim)
{
  if (htim->Instance == TIM1)
  {
    HAL_IncTick();
  }
}

/**
  * @brief  This function is executed in case of error occurrence.
  * @retval None
  */
void Error_Handler(void)
{
  /* USER CODE BEGIN Error_Handler_Debug */
  /* User can add his own implementation to report the HAL error return state */
  __disable_irq();
  while (1)
  {
  }
  /* USER CODE END Error_Handler_Debug */
}
#ifdef USE_FULL_ASSERT
/**
  * @brief  Reports the name of the source file and the source line number
  *         where the assert_param error has occurred.
  * @param  file: pointer to the source file name
  * @param  line: assert_param error line source number
  * @retval None
  */
void assert_failed(uint8_t *file, uint32_t line)
{
  /* USER CODE BEGIN 6 */
  /* User can add his own implementation to report the file name and line number,
     ex: printf("Wrong parameters value: file %s on line %d\r\n", file, line) */
  /* USER CODE END 6 */
}
#endif /* USE_FULL_ASSERT */

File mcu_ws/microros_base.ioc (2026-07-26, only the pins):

Mcu.UserName=STM32H533RETx
PA0.Signal=S_TIM5_CH1
PA1.Signal=S_TIM5_CH2
PA11.Signal=FDCAN1_RX
PA12.Signal=FDCAN1_TX
PA13(JTMS/SWDIO).Signal=DEBUG_JTMS-SWDIO
PA14(JTCK/SWCLK).Signal=DEBUG_JTCK-SWCLK
PA15(JTDI).Signal=S_TIM2_CH1
PA2.Signal=USART2_TX
PA3.Signal=USART2_RX
PA5.GPIO_Label=USER_LED
PA5.Signal=GPIO_Output
PB10.GPIO_Label=cs_imu
PB10.Signal=GPIO_Output
PB2.Signal=SPI2_SCK
PB3(JTDO/TRACESWO).Signal=S_TIM2_CH2
PB6.Signal=I2C1_SCL
PB7.Signal=I2C1_SDA
PC1.Signal=SPI2_MOSI
PC2.Signal=SPI2_MISO
PH0-OSC_IN(PH0).Signal=RCC_OSC_IN
PH1-OSC_OUT(PH1).Signal=RCC_OSC_OUT

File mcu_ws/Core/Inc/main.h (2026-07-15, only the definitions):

#define USER_LED_Pin GPIO_PIN_5
#define USER_LED_GPIO_Port GPIOA
#define cs_imu_Pin GPIO_PIN_10
#define cs_imu_GPIO_Port GPIOB

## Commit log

2026-05-29 add table
    [table.urdf.xacro]
2026-07-08 add io
    [Banebots_t81_Wheel_2_875x_8.stl, Part_1.stl, Part_1_1.stl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]
2026-07-20 Remove init of timer 2 and 5 as it is the start function to be called
2026-07-21 Compile arm_matrix and change uart Baudrate
    add include Driver/DSP/Include/dsp to Makefile
    add MatrixFunction.c to Makefile
    change usart2 baudrate to 2000000 for faster micro-ros communication
    clean icm32688.c
2026-07-25 solve crash issue and add working debug config
    [stm32h5x.cfg]
2026-07-26 fix serial prints
2026-08-07 fix bad wheel speed calculation
    [app_freertos.c]
2026-10-28 add motor control project
2026-11-07 feat: new Bedenes pcb

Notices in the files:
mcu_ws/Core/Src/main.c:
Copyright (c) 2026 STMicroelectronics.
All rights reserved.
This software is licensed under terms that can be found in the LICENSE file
